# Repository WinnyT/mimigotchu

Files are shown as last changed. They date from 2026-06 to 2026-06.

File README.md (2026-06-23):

# Mimigotchu: a non-distractible reminder
This pet will help me reduce my screen time by playing hide-and-seek with me, so I can stay away from my phone! To be specific, they will play sound when I was doing a task for too long and run away so have to stand up and find them. Potential turn into a stress reliever.



# How to build
1. 3D print the pet case and wheels
2. Solder all the component of the PCB on to the PCB
   1. XIAO ESP32-C6 (SMD, center of board)
   2. L293D motor driver (U3)
   3. OLED header pins (U2)
   4. Buttons SW1, SW2, SW3
   5. Buzzer (BUZZER1)
   6. Battery connector (BT1)
   7. Motor connector (M1)
4. Screw the PCB on to the upper case using the M3 bolt 
5. Put on the rubber band to the wheels
6. Place the motor on the **Right Bottom** corner, it should fit the motor holder case
7. Put the stick in between the hole. **THEN** put on the wheels. Do the same for both front and back
8. Snap 2 case todether and connect the pet to your computer with a type-c cable
9. Download the firmware file and upload it to XIAO ESP32

# How to use
There are 3 buttons from LEFT to RIGHT. I'll call them Left - Middle - Right

Left Button: 
Short press - +1 minute

Middle Button: 
Short press - +1 second

Right Button:
Short press - Start countdown
Long press - Switch to pet screen

Left & Middle Button - Reset Timer

Oled screen:
Timer mode: showing countdown of the timer MM:SS
Pet mode: showing hapiness and age

**MIMI will run away when the timer is UP**

# Why I make this
I found myself addicted to phone, and I have tried many ways to reduce my screen time like set a timer or use a timer lock down. But it never work. The problem I found with setting a timer is I leave it by my side, so it was too easy for me to turn it off and not getting away from my phone. I hope this robot can run away, make me stand up and catch them. _Sounds silly but what if it works ?.?_

# CAD 



[Link](https://cad.onshape.com/documents/3b2edbb59c71210e96e39001/w/2137fb4aa4ad6a67b537fdc8/e/cc7023662d27975941fd0b95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) to Onshape design. 

# PCB

[Download gebber file](https://github.com/WinnyT/mimigotchu/blob/main/assets/pcb/gebber/gebber.zip)
### 3D view of the PCB

Front



Back



### 3D model after assembly the PCB
Front



Back



### Schematic



# Firmware

You can flash Mimigotchi without installing PlatformIO.

[Download latest firmware](https://github.com/WinnyT/mimigotchu/releases/tag/v1.0.1)

### Flash instructions (macOS/Windows/Linux)
1. Install [esptool](https://docs.espressif.com/projects/esptool/en/latest/) via terminal:

pip install esptool

2. Connect your Mimigotchi via USB-C
3. Download `bootloader.bin`, `partitions.bin`, and `firmware.bin` from the release
4. Run (from the folder containing all three files):
esptool.py --port /dev/tty.usbmodem* write_flash 

0x0     bootloader.bin 

0x8000  partitions.bin 

0x10000 firmware.bin
   On Windows, replace `/dev/tty.usbmodem*` with `COM3`
   
### Build from source
If you want to modify the code, open the project in VS Code with PlatformIO installed and press `Ctrl+Alt+B` to build, then `Ctrl+Alt+U` to upload.

# BOM
Check out `mimigotchu_bom.csv` or [this](https://docs.google.com/spreadsheets/d/1_V7xxnciXNeib1qt1jn1ameioscYv5FXHhLbUMrxZ48/edit?usp=sharing) link.

# Easter Egg
If you finished a study session ( 50+ minutes) your pet will be happier !!

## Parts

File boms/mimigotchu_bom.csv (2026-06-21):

Name | Part number | Description | Link | Cost | Amount | Price | Total
Buzzer | HC-9042 | Playsound | https://www.aliexpress.us/item/3256806074013807.html?curPageLogUid=D74mWIDIXteV | 0.95 | 1 | 0.95 | 32.42
OLED Screen | SSD1306 0.96" I2C | Display the timer and pet status | https://www.aliexpress.us/item/3256808873087768.html?curPageLogUid=fpQSw2OR1A79 | 0.99 | 1 | 0.99
Button | 4x4x2.5mm SPST tactile switch | Button to control the watch, 4*4*2.5 | https://www.aliexpress.us/item/3256801545221648.html?curPageLogUid=6XJ7cagEYMcl | 3.69 | 1 | 3.69
Rubber O-ring |  | Add grips to the wheels | https://www.aliexpress.us/item/3256808533202321.html?curPageLogUid=z8sGa4KTqiAh | 0.99 | 1 | 0.99
Battery | 3.7V 2000mAh LiPo | Energy storage | https://www.aliexpress.us/item/3256802733222186.html?curPageLogUid=jtczM7dNZdCN | 7.89 | 1 | 7.89
PCB |  | Custom PCB from JLCPCB | https://cart.jlcpcb.com/quote?stencilLayer=2&stencilWidth=35&stencilLength=83&stencilCounts=5&plateType=1 | 2 | 1 | 2
Motor | N20 3.6V 230RPM | Move the pet | https://www.aliexpress.us/item/3256806897423205.html?curPageLogUid=CbjxVEBztWhg | 6.45 | 1 | 6.45
M3 x 5mm Bolt |  | Secure the PCB on to the case | https://www.aliexpress.us/item/2255800885711092.html?curPageLogUid=Trywy83H6MFZ | 1.54 | 1 | 1.54
XIAO ESP32-C3 |  | Microcontroller | https://www.seeedstudio.com/Seeed-XIAO-ESP32C3-p-5431.html | 4.74 | 1 | 4.74
L293D | L293 DIP-16 | Motor Controller | https://www.aliexpress.us/item/3256808256807059.html?curPageLogUid=QxiNZqzTo94H | 3.18 | 1 | 3.18

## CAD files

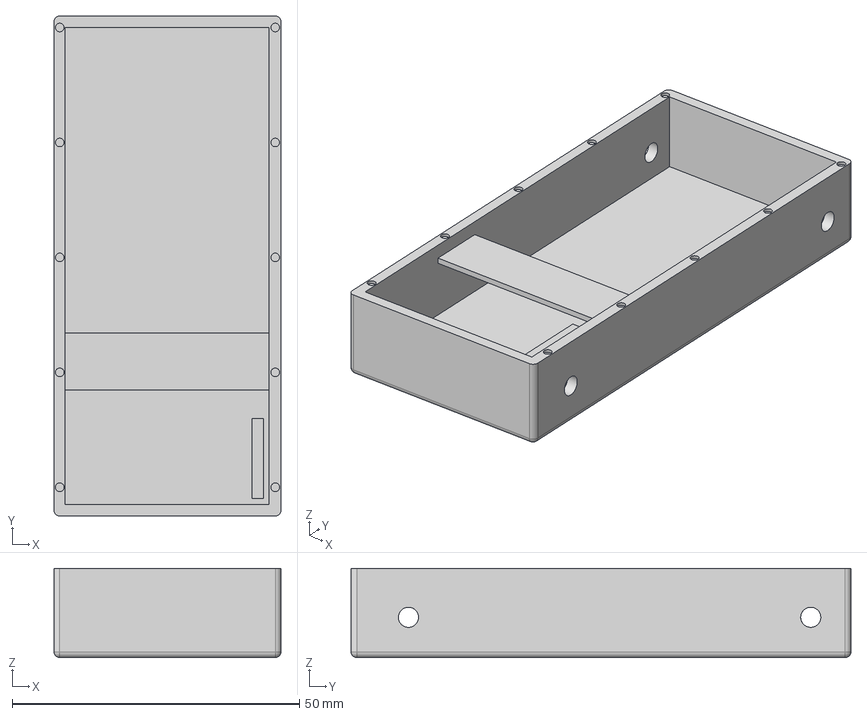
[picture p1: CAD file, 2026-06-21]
assets/cad/bottom_case.step
39.5 x 87.0 x 15.5 mm

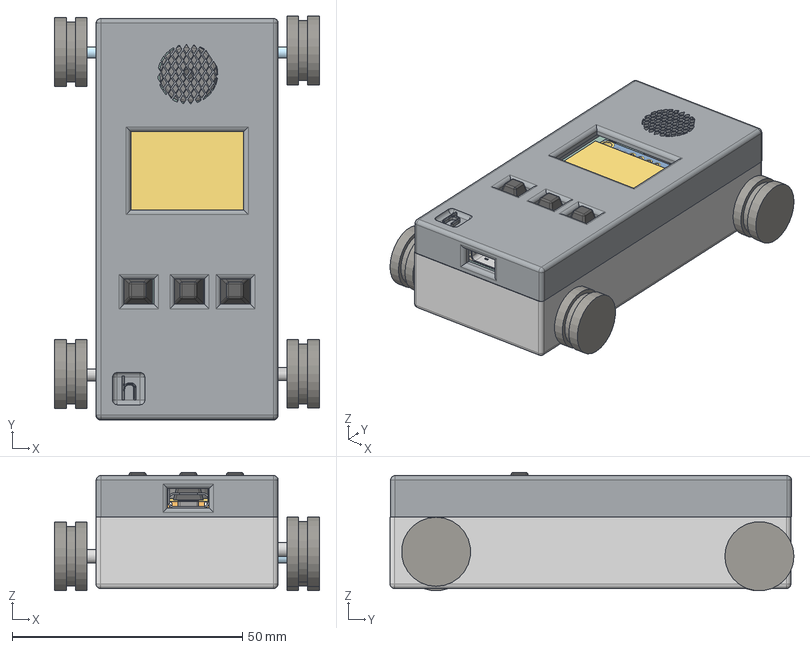
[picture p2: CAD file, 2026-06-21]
assets/cad/mimigotchu.step
57.5 x 87.7 x 25.6 mm
Battery v4 x 3
BUZ-TH_BD12.5-H7.0-P6.5
OLED-TH_L27.8-W27.2-P2.54_C9900033791
mimigotchi_PCB
Seeed Studio XIAO-ESP32-C3 v15
DIP-16_L20.0-W6.4-H3.5-LS7.62-P2.54

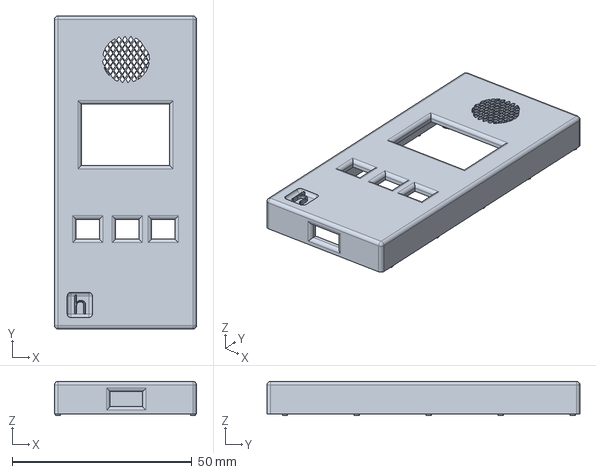
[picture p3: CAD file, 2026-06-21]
assets/cad/top_case.step
39.5 x 87.0 x 9.50 mm

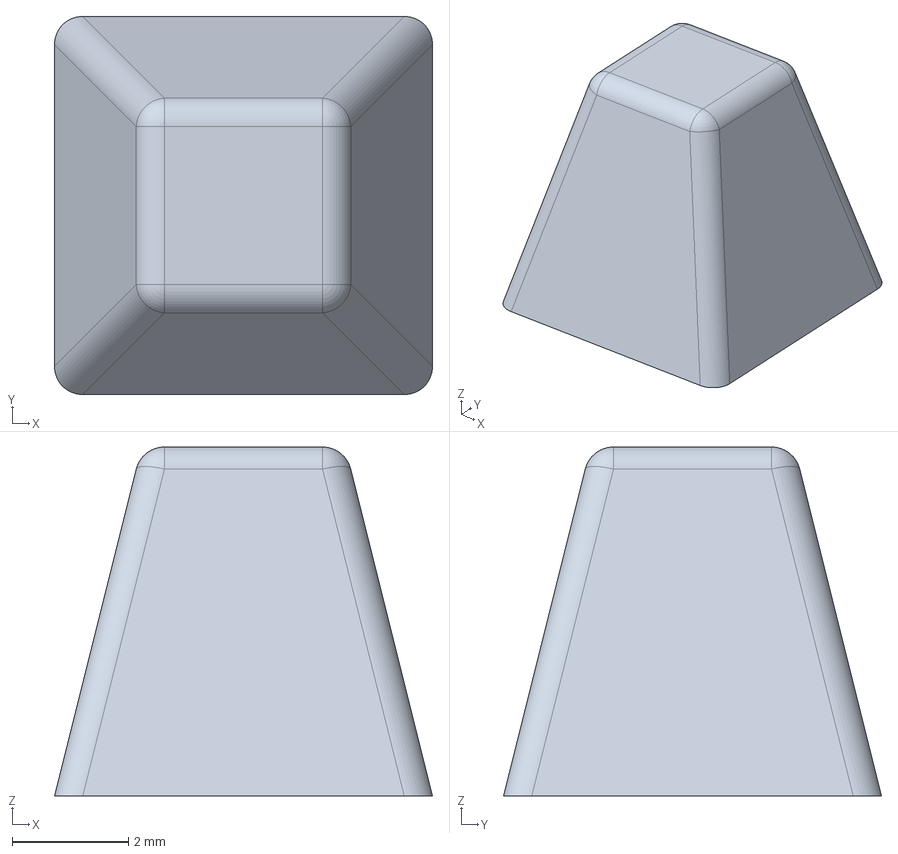
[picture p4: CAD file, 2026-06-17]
assets/cad/button_cap.step
6.50 x 6.50 x 6.00 mm

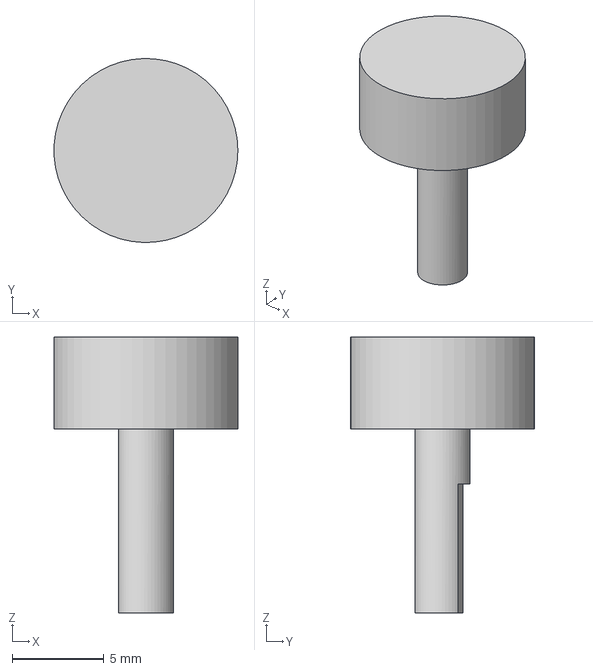
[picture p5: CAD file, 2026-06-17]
assets/cad/back_wheel_connector.step
9.99 x 10.00 x 15.0 mm

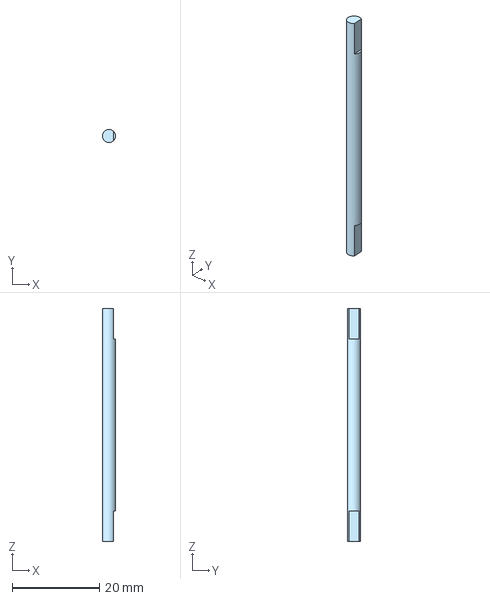
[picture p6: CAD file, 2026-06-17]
assets/cad/front_wheel_connector.step
3.00 x 3.00 x 53.5 mm

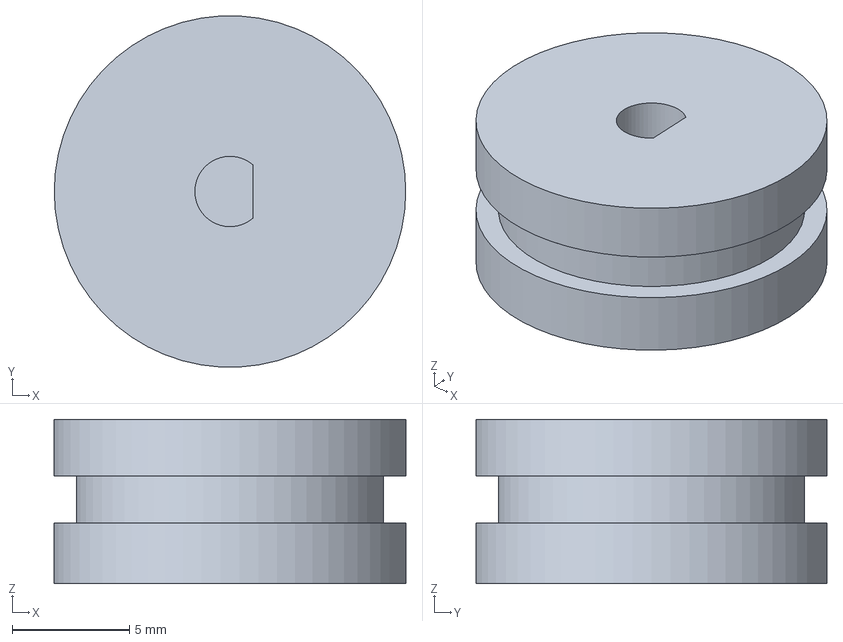
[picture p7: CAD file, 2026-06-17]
assets/cad/wheel.step
15.0 x 15.0 x 7.00 mm

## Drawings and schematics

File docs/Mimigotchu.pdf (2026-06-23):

# MMIIMMIIGGOOTTCCHHUU

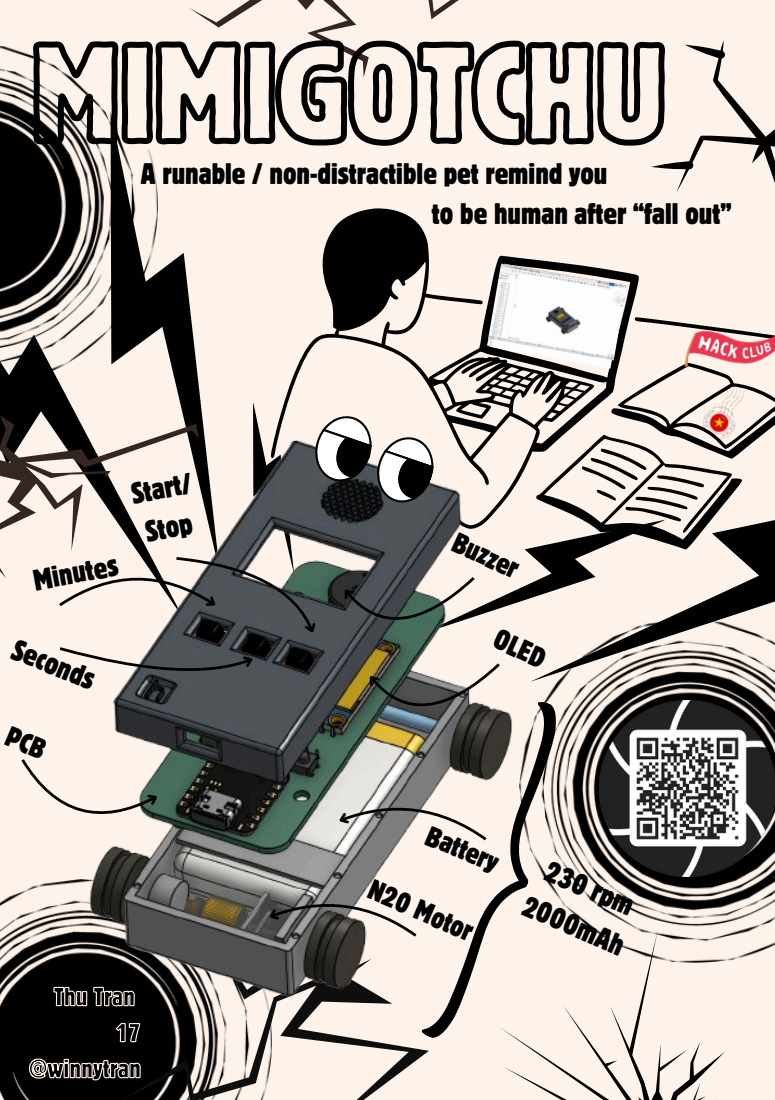
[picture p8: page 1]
N20 Motor; PCB; Battery; Minutes; OLED; Buzzer; TThhuu TTrraann 17 @@wwiinnnnyyttrraann; Seconds; rpm 000mAh; Start/ Stop

A runable / non-distractible pet remind you

to be human after “fall out”

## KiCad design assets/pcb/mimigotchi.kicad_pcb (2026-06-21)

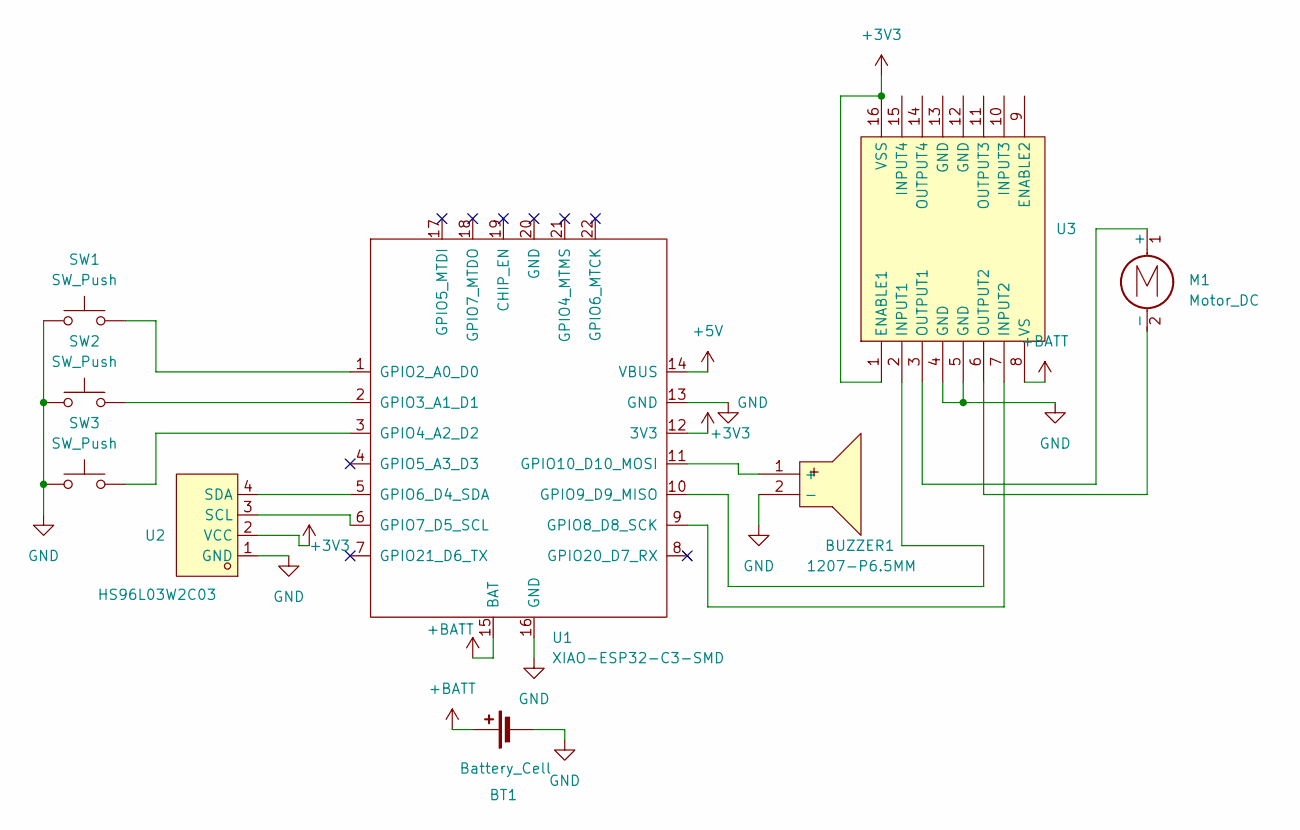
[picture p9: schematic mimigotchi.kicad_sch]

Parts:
BT1: Battery_Cell; PinHeader_1x02_P2.54mm_Vertical
BUZZER1: 1207-P6.5MM; BUZ-TH_BD12.5-P6.50-D1.4; MPN 1207-P6.5MM; LCSC Part C49246964
M1: Motor_DC; PinHeader_1x02_P2.54mm_Vertical
SW1, SW2, SW3: SW_Push; SW-TH_4P-L4.5-W4.5-P3.00-LS4.8
U1: XIAO-ESP32-C3-SMD
U2: HS96L03W2C03; OLED-TH_L27.8-W27.2-P2.54_C9900033791; MPN HS96L03W2C03; LCSC Part C5248080
U3: L293D; DIP-16_L20.0-W6.4-P2.54-LS7.6-BL; MPN L293D; LCSC Part C12340

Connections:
+3V3: U1.12 (3V3), U2.2 (VCC), U3.1 (ENABLE1), U3.16 (VSS)
+5V: U1.14 (VBUS)
+BATT: BT1.1 (+), U1.15 (BAT), U3.8 (VS)
GND: BT1.2 (-), BUZZER1.2 (-), SW1.1, SW2.1, SW3.1, U1.13 (GND), U1.16 (GND), U2.1 (GND), U3.4 (GND), U3.5 (GND)
unnamed: BUZZER1.1 (+), U1.11 (GPIO10_D10_MOSI)
unnamed: M1.1 (+), U3.3 (OUTPUT1)
unnamed: M1.2 (-), U3.6 (OUTPUT2)
unnamed: SW1.2, U1.1 (GPIO2_A0_D0)
unnamed: SW2.2, U1.2 (GPIO3_A1_D1)
unnamed: SW3.2, U1.3 (GPIO4_A2_D2)
unnamed: U1.5 (GPIO6_D4_SDA), U2.4 (SDA)
unnamed: U1.6 (GPIO7_D5_SCL), U2.3 (SCL)
unnamed: U1.9 (GPIO8_D8_SCK), U3.7 (INPUT2)
unnamed: U1.10 (GPIO9_D9_MISO), U3.2 (INPUT1)

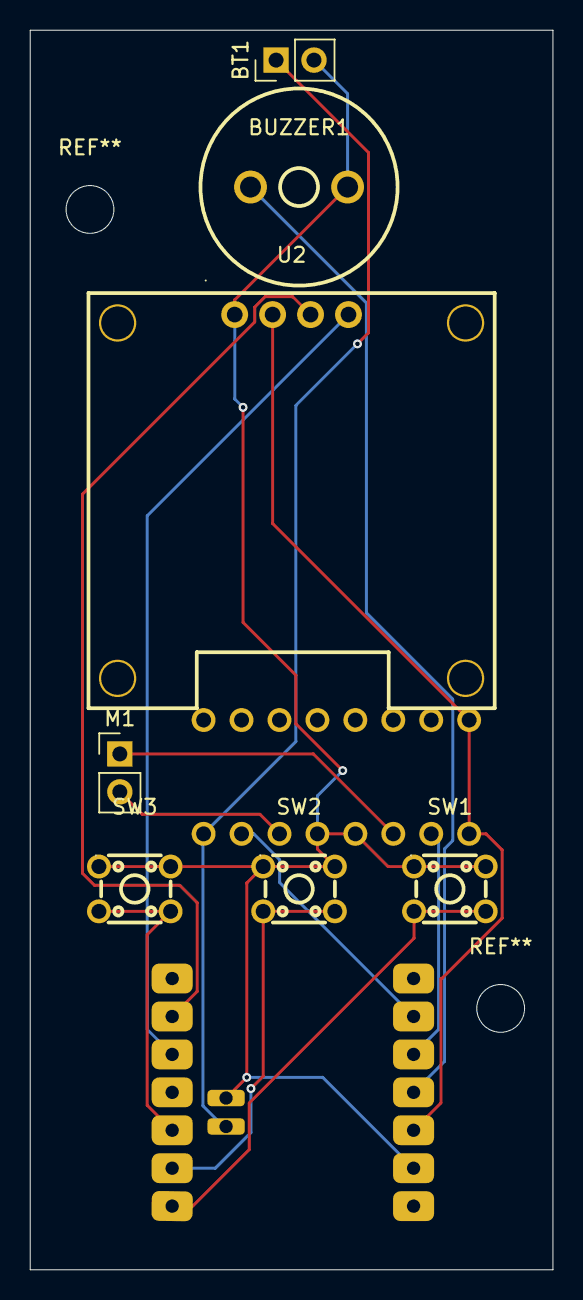
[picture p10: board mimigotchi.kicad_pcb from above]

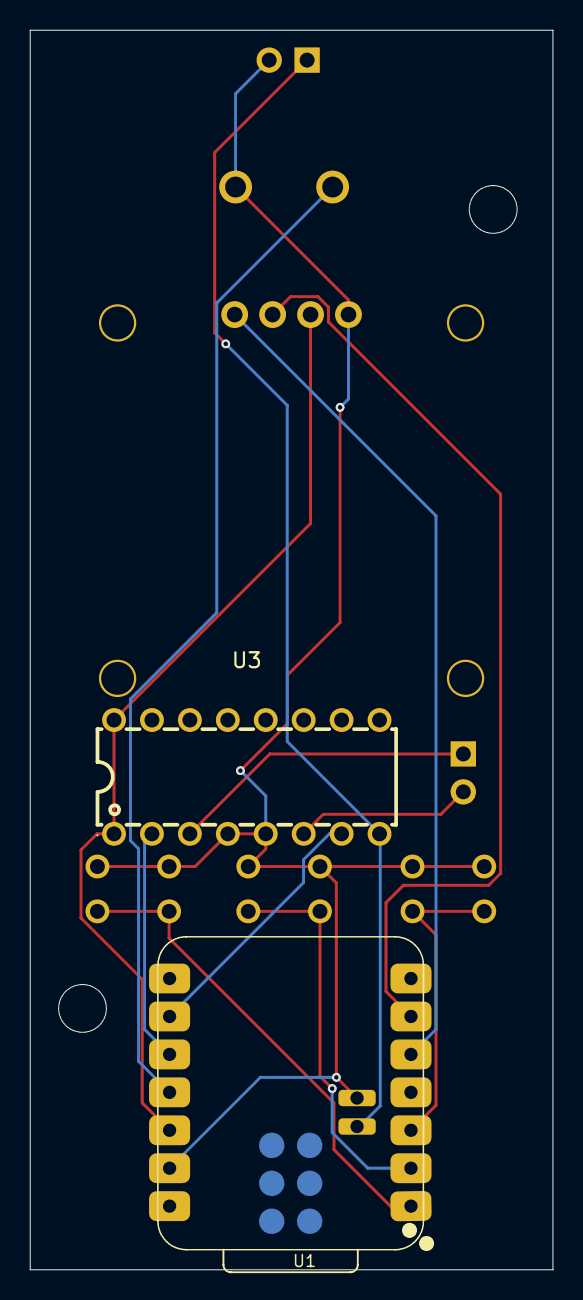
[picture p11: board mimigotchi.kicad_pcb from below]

Board: 2 copper layers, 35.0 x 83.0 mm, 9 parts (2 on the bottom side), 13 nets.

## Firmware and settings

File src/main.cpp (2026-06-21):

#include "freertos/FreeRTOS.h"
#include "freertos/task.h"
#include "driver/i2c.h"
#include "driver/gpio.h"
#include "esp_timer.h"
#include "esp_rom_sys.h"
#include <string.h>
#include <stdio.h>

// ─── Pins ──────────────────────────────────────────────────────────
#define BTN_RIGHT    GPIO_NUM_2    
#define BTN_MIDDLE   GPIO_NUM_3    
#define BTN_LEFT     GPIO_NUM_4    
#define BUZZER_PIN   GPIO_NUM_10   
#define SDA_PIN      GPIO_NUM_6    
#define SCL_PIN      GPIO_NUM_7    
#define MOTOR_INPUT1 GPIO_NUM_9    
#define MOTOR_INPUT2 GPIO_NUM_8    

// ─── I2C / OLED ────────────────────────────────────────────────────
#define I2C_PORT     I2C_NUM_0
#define OLED_ADDR    0x3C
#define OLED_WIDTH   128
#define OLED_PAGES   8       // 64px height / 8px per page

static uint8_t framebuf[OLED_WIDTH * OLED_PAGES];  // 1 bit per pixel

// ── Raw I2C helpers ────────────────────────────────────────────────
static void i2c_init() {
    i2c_config_t cfg = {
        .mode             = I2C_MODE_MASTER,
        .sda_io_num       = SDA_PIN,
        .scl_io_num       = SCL_PIN,
        .sda_pullup_en    = GPIO_PULLUP_ENABLE,
        .scl_pullup_en    = GPIO_PULLUP_ENABLE,
        .master = { .clk_speed = 400000 },
        .clk_flags        = 0
    };
    i2c_param_config(I2C_PORT, &cfg);
    i2c_driver_install(I2C_PORT, I2C_MODE_MASTER, 0, 0, 0);
}

static void oled_cmd(uint8_t cmd) {
    uint8_t buf[2] = { 0x00, cmd };
    i2c_master_write_to_device(I2C_PORT, OLED_ADDR, buf, 2, pdMS_TO_TICKS(10));
}

static void oled_init() {
    vTaskDelay(pdMS_TO_TICKS(100));
    const uint8_t cmds[] = {
        0xAE,       // display off
        0xD5, 0x80, // clock divide
        0xA8, 0x3F, // multiplex ratio (64-1)
        0xD3, 0x00, // display offset
        0x40,       // start line
        0x8D, 0x14, // charge pump on
        0x20, 0x00, // horizontal addressing
        0xA1,       // segment remap
        0xC8,       // com scan direction
        0xDA, 0x12, // com pins
        0x81, 0xCF, // contrast
        0xD9, 0xF1, // precharge
        0xDB, 0x40, // vcomh
        0xA4,       // output follows RAM
        0xA6,       // normal (not inverted)
        0xAF        // display on
    };
    for (size_t i = 0; i < sizeof(cmds); i++) oled_cmd(cmds[i]);
}

static void oled_flush() {
    // Set full address window
    oled_cmd(0x21); oled_cmd(0); oled_cmd(127);  // columns 0-127
    oled_cmd(0x22); oled_cmd(0); oled_cmd(7);    // pages 0-7

    // Send framebuffer in 16-byte chunks
    uint8_t chunk[17];
    chunk[0] = 0x40;   // data mode
    for (int i = 0; i < OLED_WIDTH * OLED_PAGES; i += 16) {
        memcpy(&chunk[1], &framebuf[i], 16);
        i2c_master_write_to_device(I2C_PORT, OLED_ADDR, chunk, 17, pdMS_TO_TICKS(10));
    }
}

// ─── Drawing primitives ────────────────────────────────────────────
static void fb_clear() {
    memset(framebuf, 0, sizeof(framebuf));
}

static void fb_pixel(int x, int y, bool on) {
    if (x < 0 || x >= OLED_WIDTH || y < 0 || y >= 64) return;
    int page = y / 8;
    int bit  = y % 8;
    if (on) framebuf[page * OLED_WIDTH + x] |=  (1 << bit);
    else    framebuf[page * OLED_WIDTH + x] &= ~(1 << bit);
}

static void fb_rect(int x, int y, int w, int h, bool filled) {
    for (int row = y; row < y + h; row++)
        for (int col = x; col < x + w; col++)
            if (filled || row == y || row == y+h-1 || col == x || col == x+w-1)
                fb_pixel(col, row, true);
}

// 5x7 font — ASCII 32-127
static const uint8_t font5x7[][5] = {
    {0x00,0x00,0x00,0x00,0x00}, // space
    {0x00,0x00,0x5F,0x00,0x00}, // !
    {0x00,0x07,0x00,0x07,0x00}, // "
    {0x14,0x7F,0x14,0x7F,0x14}, // #
    {0x24,0x2A,0x7F,0x2A,0x12}, // $
    {0x23,0x13,0x08,0x64,0x62}, // %
    {0x36,0x49,0x55,0x22,0x50}, // &
    {0x00,0x05,0x03,0x00,0x00}, // '
    {0x00,0x1C,0x22,0x41,0x00}, // (
    {0x00,0x41,0x22,0x1C,0x00}, // )
    {0x14,0x08,0x3E,0x08,0x14}, // *
    {0x08,0x08,0x3E,0x08,0x08}, // +
    {0x00,0x50,0x30,0x00,0x00}, // ,
    {0x08,0x08,0x08,0x08,0x08}, // -
    {0x00,0x60,0x60,0x00,0x00}, // .
    {0x20,0x10,0x08,0x04,0x02}, // /
    {0x3E,0x51,0x49,0x45,0x3E}, // 0
    {0x00,0x42,0x7F,0x40,0x00}, // 1
    {0x42,0x61,0x51,0x49,0x46}, // 2
    {0x21,0x41,0x45,0x4B,0x31}, // 3
    {0x18,0x14,0x12,0x7F,0x10}, // 4
    {0x27,0x45,0x45,0x45,0x39}, // 5
    {0x3C,0x4A,0x49,0x49,0x30}, // 6
    {0x01,0x71,0x09,0x05,0x03}, // 7
    {0x36,0x49,0x49,0x49,0x36}, // 8
    {0x06,0x49,0x49,0x29,0x1E}, // 9
    {0x00,0x36,0x36,0x00,0x00}, // :
    {0x00,0x56,0x36,0x00,0x00}, // ;
    {0x08,0x14,0x22,0x41,0x00}, // 
    {0x14,0x14,0x14,0x14,0x14}, // =
    {0x00,0x41,0x22,0x14,0x08}, // >
    {0x02,0x01,0x51,0x09,0x06}, // ?
    {0x32,0x49,0x79,0x41,0x3E}, // @
    {0x7E,0x11,0x11,0x11,0x7E}, // A
    {0x7F,0x49,0x49,0x49,0x36}, // B
    {0x3E,0x41,0x41,0x41,0x22}, // C
    {0x7F,0x41,0x41,0x22,0x1C}, // D
    {0x7F,0x49,0x49,0x49,0x41}, // E
    {0x7F,0x09,0x09,0x09,0x01}, // F
    {0x3E,0x41,0x49,0x49,0x7A}, // G
    {0x7F,0x08,0x08,0x08,0x7F}, // H
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
    {0x02,0x04,0x08,0x10,0x20}, // backslash
    {0x00,0x41,0x41,0x7F,0x00}, // ]
    {0x04,0x02,0x01,0x02,0x04}, // ^
    {0x40,0x40,0x40,0x40,0x40}, // _
    {0x00,0x01,0x02,0x04,0x00}, // `
    {0x20,0x54,0x54,0x54,0x78}, // a
    {0x7F,0x48,0x44,0x44,0x38}, // b
    {0x38,0x44,0x44,0x44,0x20}, // c
    {0x38,0x44,0x44,0x48,0x7F}, // d
    {0x38,0x54,0x54,0x54,0x18}, // e
    {0x08,0x7E,0x09,0x01,0x02}, // f
    {0x0C,0x52,0x52,0x52,0x3E}, // g
    {0x7F,0x08,0x04,0x04,0x78}, // h
    {0x00,0x44,0x7D,0x40,0x00}, // i
    {0x20,0x40,0x44,0x3D,0x00}, // j
    {0x7F,0x10,0x28,0x44,0x00}, // k
    {0x00,0x41,0x7F,0x40,0x00}, // l
    {0x7C,0x04,0x18,0x04,0x78}, // m
    {0x7C,0x08,0x04,0x04,0x78}, // n
    {0x38,0x44,0x44,0x44,0x38}, // o
    {0x7C,0x14,0x14,0x14,0x08}, // p
    {0x08,0x14,0x14,0x18,0x7C}, // q
    {0x7C,0x08,0x04,0x04,0x08}, // r
    {0x48,0x54,0x54,0x54,0x20}, // s
    {0x04,0x3F,0x44,0x40,0x20}, // t
    {0x3C,0x40,0x40,0x40,0x3C}, // u
    {0x1C,0x20,0x40,0x20,0x1C}, // v
    {0x3C,0x40,0x30,0x40,0x3C}, // w
    {0x44,0x28,0x10,0x28,0x44}, // x
    {0x0C,0x50,0x50,0x50,0x3C}, // y
    {0x44,0x64,0x54,0x4C,0x44}, // z
};

static void fb_char(int x, int y, char c) {
    if (c < 32 || c > 122) return;
    const uint8_t* glyph = font5x7[c - 32];
    for (int col = 0; col < 5; col++) {
        uint8_t bits = glyph[col];
        for (int row = 0; row < 7; row++)
            fb_pixel(x + col, y + row, (bits >> row) & 1);
    }
}

static void fb_str(int x, int y, const char* s) {
    while (*s) { fb_char(x, y, *s++); x += 6; }
}

static void fb_bar(int x, int y, int w, int h, int value) {
    fb_rect(x, y, w, h, false);                        // outline
    int fill = (value * (w - 2)) / 100;
    if (fill > 0) fb_rect(x + 1, y + 1, fill, h - 2, true);  // fill
}

// ─── Sprites (16x16) ───────────────────────────────────────────────
// Each sprite: 16 rows, each row is a uint16_t bitmask (bit15 = leftmost pixel)
static const uint16_t sprHappy[16] = {
    0x0000, 0x1FF0, 0x2008, 0x4004,
    0x4CD2, 0x4CD2, 0x4002, 0x4002,
    0x4222, 0x41C2, 0x4002, 0x2008,
    0x1FF0, 0x0000, 0x0000, 0x0000
};
static const uint16_t sprSad[16] = {
    0x0000, 0x1FF0, 0x2008, 0x4004,
    0x4CD2, 0x4CD2, 0x4002, 0x4002,
    0x4002, 0x41C2, 0x4222, 0x2008,
    0x1FF0, 0x0000, 0x0000, 0x0000
};
static const uint16_t sprNeutral[16] = {
    0x0000, 0x1FF0, 0x2008, 0x4004,
    0x4CD2, 0x4CD2, 0x4002, 0x4002,
    0x43E2, 0x4002, 0x4002, 0x2008,
    0x1FF0, 0x0000, 0x0000, 0x0000
};

static void fb_sprite(int x, int y, const uint16_t* spr) {
    for (int row = 0; row < 16; row++)
        for (int col = 0; col < 16; col++)
            fb_pixel(x + col, y + row, (spr[row] >> (15 - col)) & 1);
}

// ─── App State ─────────────────────────────────────────────────────
enum AppMode { MODE_TIMER, MODE_PET };
static AppMode currentMode = MODE_TIMER;

struct Pet { int happiness; unsigned long age; };
static Pet pet = { 80, 0 };

enum Screen { SCREEN_MAIN, SCREEN_PLAY };
static Screen currentScreen = SCREEN_MAIN;

static bool canFeed      = false;
static bool motorRunning = false;

// Timer
static int  timerMinutes = 0;
static int  timerSeconds = 0;
static int initialTimerMinutes = 0;
static bool timerRunning = false;
static bool timerDone    = false;
static bool study_session_active = false;
static unsigned long lastTimerTick = 0;
static unsigned long lastPetUpdate = 0;

// Button tracking
static unsigned long lastButtonPress   = 0;
static unsigned long btnRightHoldStart = 0;
static bool          btnRightHeld      = false;

// ─── Helpers ───────────────────────────────────────────────────────
static unsigned long millis_now() {
    return (unsigned long)(esp_timer_get_time() / 1000ULL);
}

static void playTone(int freq_hz, int duration_ms) {
    int half_us = 1000000 / (freq_hz * 2);
    int cycles  = (freq_hz * duration_ms) / 1000;
    for (int i = 0; i < cycles; i++) {
        gpio_set_level(BUZZER_PIN, 1);
        esp_rom_delay_us(half_us);
        gpio_set_level(BUZZER_PIN, 0);
        esp_rom_delay_us(half_us);
    }
}

static void startMotor() {
    gpio_set_level(MOTOR_INPUT1, 1);
    gpio_set_level(MOTOR_INPUT2, 0);
    motorRunning = true;
}

static void stopMotor() {
    gpio_set_level(MOTOR_INPUT1, 0);
    gpio_set_level(MOTOR_INPUT2, 0);
    motorRunning = false;
}

// ─── Timer logic ───────────────────────────────────────────────────
static void onTimerComplete() {
    canFeed      = true;
    timerDone    = true;
    timerRunning = false;
    playTone(1000, 500);
    startMotor();

    if (study_session_active) {
        // If it was a study session, give extra happiness boost
        pet.happiness += 30;
        if (pet.happiness > 100) pet.happiness = 100;
    }
}

static void updateTimer() {
    if (!timerRunning || timerDone) return;
    if (millis_now() - lastTimerTick >= 1000) {
        lastTimerTick = millis_now();
        if (timerSeconds > 0) {
            timerSeconds--;
        } else if (timerMinutes > 0) {
            timerMinutes--;
            timerSeconds = 59;
        } else {
            onTimerComplete();
        }
    }
}

static void renderTimer() {
    fb_clear();

    char buf[16];
    // Big MM:SS in the center
    snprintf(buf, sizeof(buf), "%02d:%02d", timerMinutes, timerSeconds);
    fb_str(34, 24, buf);   // x=34 centers 5 chars * 6px = 30px in 128px

    fb_str(0, 0, timerRunning ? "  TIMER RUNNING" : (timerDone ? "  TIMER DONE!" : "  SET TIMER"));

    fb_str(0, 56, timerDone ? "Long press: pet side" : "+M   +S   Start/Stop");

    oled_flush();
}

// ─── Pet logic ─────────────────────────────────────────────────────
static void updatePet() {
    if (millis_now() - lastPetUpdate > 10000) {
        pet.happiness--;
        if (pet.happiness < 0) pet.happiness = 0;
        pet.age += 10;
        lastPetUpdate = millis_now();
    }
}

static void handleScreenLogic() {
    if (currentScreen == SCREEN_PLAY) {
        if (canFeed) {
            pet.happiness += 20;
            if (pet.happiness > 100) pet.happiness = 100;
            canFeed = false;
            playTone(1500, 100);
        }
        currentScreen = SCREEN_MAIN;
    }
}

static void renderPet() {
    fb_clear();

    const uint16_t* spr = (pet.happiness < 30) ? sprSad
                        : (pet.happiness >= 60) ? sprHappy
                        :                         sprNeutral;
    fb_sprite(56, 1, spr);

    char buf[20];
    fb_str(0, 20, "HAP");
    fb_bar(22, 20, 80, 7, pet.happiness);

    snprintf(buf, sizeof(buf), "Age %lum", pet.age / 60);
    fb_str(0, 32, buf);

    if (canFeed)  fb_str(0, 56, "Middle=Play! (reward)");
    else          fb_str(0, 56, "Mid=Play  Long=Timer");

    oled_flush();
}

// ─── Buttons ───────────────────────────────────────────────────────
static void checkButtons() {
    unsigned long now = millis_now();

    // ── RIGHT: long press = switch mode, short press = start/stop or stop motor ──
    if (gpio_get_level(BTN_RIGHT) == 0) {
        if (btnRightHoldStart == 0) btnRightHoldStart = now;

        if (now - btnRightHoldStart > 1000 && !btnRightHeld) {
            btnRightHeld  = true;
            currentMode   = (currentMode == MODE_TIMER) ? MODE_PET : MODE_TIMER;
            playTone(900, 80);
        }
    } else {
        if (btnRightHoldStart > 0 && !btnRightHeld) {
            // Short press
            if (currentMode == MODE_TIMER && !timerDone) {
                if (!timerRunning && (timerMinutes > 0 || timerSeconds > 0)) {
                    initialTimerMinutes = timerMinutes;
                    study_session_active = (initialTimerMinutes >= 50); // Consider it a study session if 25+ mins set
                    timerRunning  = true;
                    lastTimerTick = now;
                    playTone(1200, 80);
                } else {
                    timerRunning = false;
                    playTone(600, 80);
                }
            } else if (motorRunning) {
                stopMotor();
                playTone(800, 80);
            }
        }
        btnRightHoldStart = 0;
        btnRightHeld      = false;
    }

    // Debounce for LEFT and MIDDLE
    if (now - lastButtonPress < 200) return;

    // ── LEFT + MIDDLE simultaneously: reset timer ──
    if (gpio_get_level(BTN_LEFT) == 0 && gpio_get_level(BTN_MIDDLE) == 0) {
        timerMinutes = 0; timerSeconds = 0;
        timerRunning = false; timerDone = false;
        stopMotor();
        playTone(500, 200);
        lastButtonPress = now;
        return;
    }

    // ── LEFT: +1 minute ──
    if (gpio_get_level(BTN_LEFT) == 0) {
        if (currentMode == MODE_TIMER && !timerRunning && !timerDone) {
            if (++timerMinutes > 99) timerMinutes = 99;
            playTone(1000, 40);
        }
        lastButtonPress = now;
    }
    // ── MIDDLE: +1 sec (timer) or play (pet) ──
    else if (gpio_get_level(BTN_MIDDLE) == 0) {
        if (currentMode == MODE_TIMER && !timerRunning && !timerDone) {
            if (++timerSeconds >= 60) { timerSeconds = 0; timerMinutes++; }
            playTone(1000, 40);
        } else if (currentMode == MODE_PET) {
            currentScreen = SCREEN_PLAY;
            playTone(1200, 50);
        }
        lastButtonPress = now;
    }
}

// ─── Entry point ───────────────────────────────────────────────────
extern "C" void app_main() {
    i2c_init();
    oled_init();

    // Buttons
    gpio_config_t btn_cfg = {
        .pin_bit_mask = (1ULL<<BTN_LEFT)|(1ULL<<BTN_MIDDLE)|(1ULL<<BTN_RIGHT),
        .mode         = GPIO_MODE_INPUT,
        .pull_up_en   = GPIO_PULLUP_ENABLE,
        .pull_down_en = GPIO_PULLDOWN_DISABLE,
        .intr_type    = GPIO_INTR_DISABLE
    };
    gpio_config(&btn_cfg);

    gpio_set_direction(BUZZER_PIN,   GPIO_MODE_OUTPUT);
    gpio_set_direction(MOTOR_INPUT1, GPIO_MODE_OUTPUT);
    gpio_set_direction(MOTOR_INPUT2, GPIO_MODE_OUTPUT);
    stopMotor();

    // Boot screen
    fb_clear();
    fb_str(28, 20, "Tamagotchi!");
    fb_str(16, 36, "Long press=switch");
    oled_flush();
    vTaskDelay(pdMS_TO_TICKS(1500));

    while (1) {
        checkButtons();
        if (currentMode == MODE_TIMER) {
            updateTimer();
            renderTimer();
        } else {
            updatePet();
            handleScreenLogic();
            renderPet();
        }
        vTaskDelay(pdMS_TO_TICKS(100));
    }
}

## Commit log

2026-06-11 Update README with name correction and additional info
    Corrected the project name and improved some phrasing in the README. Added a firmware section and clarified assembly instructions.
2026-06-13 Revise README with button actions and firmware details
    Updated button functions and added firmware flashing instructions.
2026-06-13 Rename Mimigotchu - Sheet1.csv to boms/Mimigotchu_bom.csv
    [Mimigotchu_bom.csv]
2026-06-17 Rename Assembly 1.step to assets/mimigotchu.step
    [Assembly 1.step, mimigotchu.step]
2026-06-17 Add download link for gebber file
    Added download link for gebber file in PCB section.
2026-06-17 Enhance README with CAD and PCB details
    Added images and sections for PCB and CAD in README.
2026-06-21 Rename file from Sheet1.csv to mimigotchu_bom.csv
    [mimigotchu_bom.csv]
